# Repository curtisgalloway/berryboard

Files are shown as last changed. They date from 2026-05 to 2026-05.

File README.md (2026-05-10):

# Berryboard

A Raspberry Pi HAT+ for ROV (remotely operated vehicle) control, with an RP2350B co-processor for hard real-time servo and sensor management.

## Overview

Berryboard sits on top of a Raspberry Pi 4 or 5 and handles the latency-sensitive workload that the Linux kernel can't guarantee: PWM servo output, sensor polling, and leak detection. The RPi handles high-level control logic over UART; the RP2350B handles everything that needs deterministic timing.

```
┌─────────────────────────────────────────────┐
│                  Raspberry Pi               │
│                  (host computer)            │
└──────────────┬──────────────────────────────┘
               │ 40-pin HAT header
┌──────────────▼──────────────────────────────┐
│                  Berryboard                  │
│                                             │
│  RP2350B ────── 8× servo outputs (PWM)      │
│           ────── IMU (ICM-42688-P, SPI)     │
│           ────── Magnetometer (MMC5983MA)   │
│           ────── 2× leak sensors (ADC)      │
│           ────── Servo power monitor (ADC)  │
│                                             │
│  TPS2121 power mux                          │
│    IN1: XT30 external servo power           │
│    IN2: RPi 5V from header                  │
│    OUT: 5V system rail                      │
│                                             │
│  6× QWIIC connectors                        │
│    3× on RPi I2C1 (GPIO2/3 on header)       │
│    3× on RP2350B I2C                        │
└─────────────────────────────────────────────┘
```

## Hardware Features

| Feature | Detail |
|---|---|
| Form factor | 65 × 56 mm RPi HAT+ |
| Co-processor | RP2350B (dual Arm Cortex-M33 / RISC-V, 520 KB SRAM) |
| Flash | W25Q16JVSS 2 MB QSPI (RP2350B) |
| EEPROM | 24LC32 (HAT ID, I2C0) |
| Servo outputs | 8 channels — 3× 1×8 Dupont block (signal / power / GND) |
| Servo power | XT30 connector, monitored via ADC |
| IMU | ICM-42688-P 6-axis (accel + gyro), SPI to RPi |
| Magnetometer | MMC5983MA 3-axis, I2C to RPi |
| QWIIC | 6× JST-SH 1 mm (3 RPi + 3 MCU) |
| Leak detection | 2× probes → RP2350B ADC |
| Status LED | WS2812B RGB (RP2350B GPIO12) |
| USB-C | USB 2.0 to RP2350B (programming / debug edge connector) |
| SWD | 4-pin header (J21) |
| Host link | UART (GPIO14/15 on 40-pin header); optional USB-C |
| Power | 5V from XT30 or RPi header, muxed by TPS2121 |
| 3.3V | AP2112K LDO from 5V system rail |

## Servo Connector

The 8 servo channels use three color-coded 1×8 Dupont headers placed side-by-side:

```
Pin:     1    2    3    4    5    6    7    8
         ┌────┬────┬────┬────┬────┬────┬────┐
Yellow   │ S0 │ S1 │ S2 │ S3 │ S4 │ S5 │ S6 │ S7 │  Signal
         ├────┼────┼────┼────┼────┼────┼────┤────┤
Red      │+V  │+V  │+V  │+V  │+V  │+V  │+V  │+V  │  SERVO_PWR
         ├────┼────┼────┼────┼────┼────┼────┤────┤
Black    │GND │GND │GND │GND │GND │GND │GND │GND │  GND
         └────┴────┴────┴────┴────┴────┴────┘────┘
```

Pin 1 = servo channel 1 (SERVO_0 net). Plug a standard 3-pin servo Dupont connector into any column.

## Repository Contents

| File | Description |
|---|---|
| `berryboard.kicad_sch` | Schematic |
| `berryboard.kicad_pcb` | PCB layout |
| `berryboard-custom.kicad_sym` | Custom KiCad symbols (TPS2121, ICM-42688-P, MMC5983MA) |
| `sym-lib-table` | KiCad symbol library table |

## Status

- [x] Schematic complete (0 ERC errors)
- [x] Footprints assigned
- [ ] PCB layout and routing
- [ ] Design rule check
- [ ] BOM verification (JLCPCB availability)
- [ ] Bring-up and testing

## Tools

Designed with [KiCad](https://www.kicad.org/) 9.x.

## License

Hardware design files are released under [CERN Open Hardware Licence Version 2 – Permissive (CERN-OHL-P)](https://ohwr.org/cern_ohl_p_v2.txt).

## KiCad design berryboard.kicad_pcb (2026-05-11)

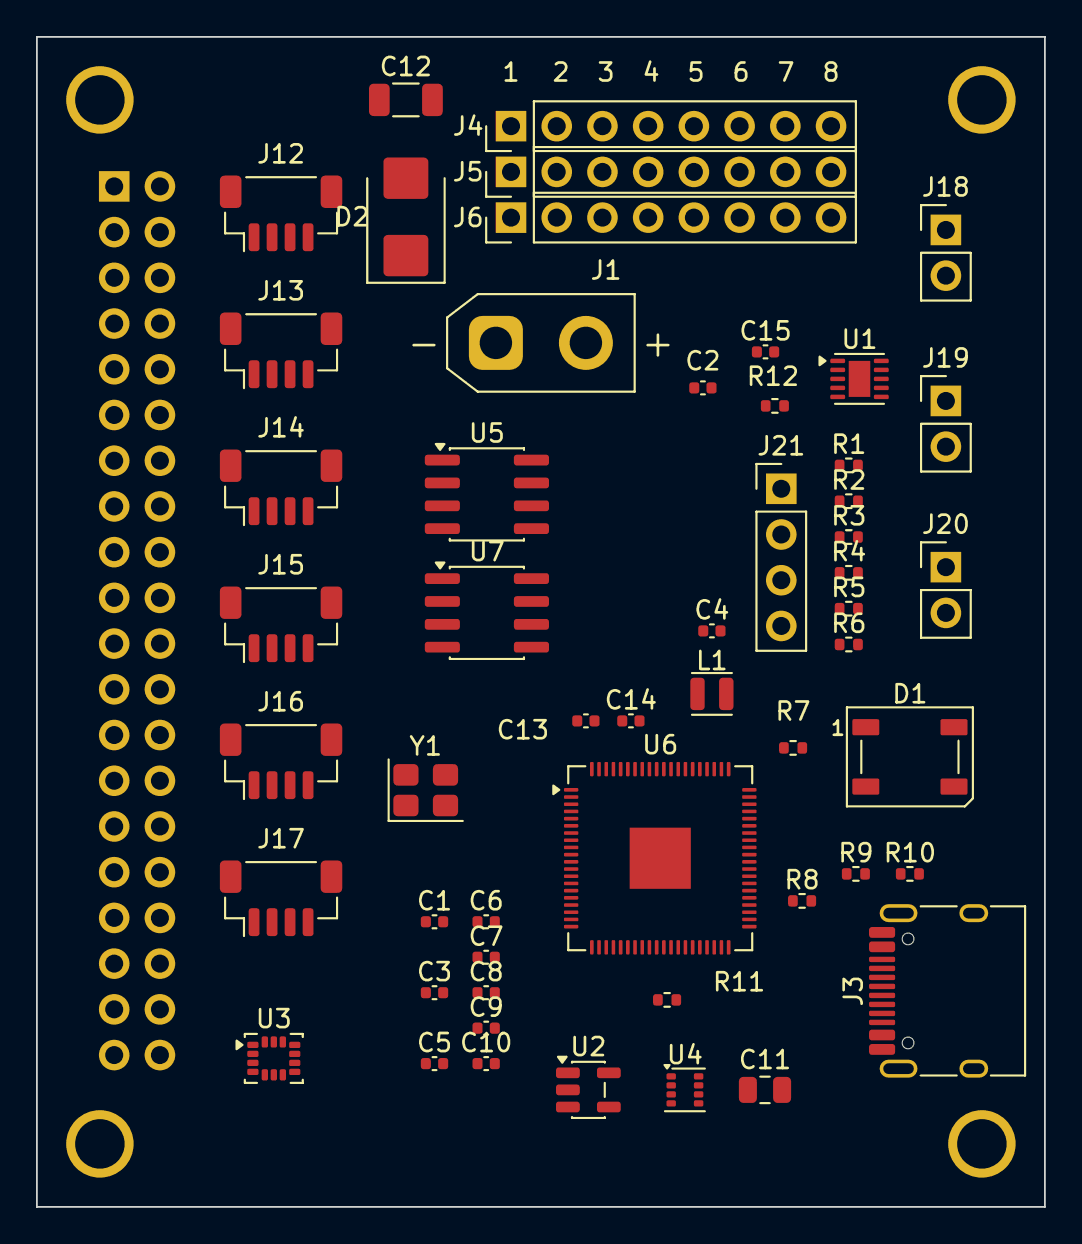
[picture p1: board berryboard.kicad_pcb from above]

Board: 2 copper layers, 56.0 x 65.0 mm, 58 parts (1 on the bottom side), 53 nets, no tracks yet.

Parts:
C1, C5, C6, C7, C8, C9: 100nF; C_0402_1005Metric
C2, C4, C15: 4.7uF; C_0402_1005Metric
C3, C10: 10uF; C_0402_1005Metric
C11: 47uF; C_0805_2012Metric
C12: 100uF; C_1206_3216Metric
C13, C14: 15pF; C_0402_1005Metric
D1: WS2812B; LED_WS2812B_PLCC4_5.0x5.0mm_P3.2mm
D2: SMBJ7.5A; D_SMB
J1: XT30_SERVO_PWR; AMASS_XT30UPB-F_1x02_P5.0mm_Vertical
J2: RPi_GPIO_40P; PinSocket_2x20_P2.54mm_Vertical
J3: USB_C_RP2350; USB_C_Receptacle_HRO_TYPE-C-31-M-12
J4: SERVO_SIG; PinHeader_1x08_P2.54mm_Vertical
J5: SERVO_PWR; PinHeader_1x08_P2.54mm_Vertical
J6: SERVO_GND; PinHeader_1x08_P2.54mm_Vertical
J12: QWIIC_RPI_1; JST_SH_BM04B-SRSS-TB_1x04-1MP_P1.00mm_Vertical
J13: QWIIC_RPI_2; JST_SH_BM04B-SRSS-TB_1x04-1MP_P1.00mm_Vertical
J14: QWIIC_RPI_3; JST_SH_BM04B-SRSS-TB_1x04-1MP_P1.00mm_Vertical
J15: QWIIC_MCU_1; JST_SH_BM04B-SRSS-TB_1x04-1MP_P1.00mm_Vertical
J16: QWIIC_MCU_2; JST_SH_BM04B-SRSS-TB_1x04-1MP_P1.00mm_Vertical
J17: QWIIC_MCU_3; JST_SH_BM04B-SRSS-TB_1x04-1MP_P1.00mm_Vertical
J18: LEAK_1; PinHeader_1x02_P2.54mm_Vertical
J19: LEAK_2; PinHeader_1x02_P2.54mm_Vertical
J20: HAT_5V_IN; PinHeader_1x02_P2.54mm_Vertical
J21: SWD; PinHeader_1x04_P2.54mm_Vertical
L1: AOTA-B201610S3R3-101-T; L_Wuerth_PMCI-201610
MH1, MH2, MH3, MH4: MountingHole_2.75mm
R1, R2: 5.1k; R_0402_1005Metric
R3, R4, R5, R6: 4.7k; R_0402_1005Metric
R7: 220k; R_0402_1005Metric
R8: 100k; R_0402_1005Metric
R9, R10: 27; R_0402_1005Metric
R11: 1k; R_0402_1005Metric
R12: 33; R_0402_1005Metric
U1: TPS2121; WSON-10-1EP_2.5x2.5mm_P0.5mm_EP1.2x2mm
U2: AP2112K-3.3; SOT-23-5
U3: ICM-42688-P; LGA-14_3x2.5mm_P0.5mm_LayoutBorder3x4y
U4: MMC5983MA; Broadcom_LGA-8_2x2mm_P0.5mm
U5: 24LC32; SOIC-8_3.9x4.9mm_P1.27mm
U6: RP2350B; QFN-80-1EP_10x10mm_P0.4mm_EP3.4x3.4mm
U7: W25Q16JVSS; SOIC-8_3.9x4.9mm_P1.27mm
Y1: ABM8-272-T3; Crystal_SMD_3225-4Pin_3.2x2.5mm

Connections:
/+3.3V_RPI: J2.1, J2.17
/+3V3: C2.1, C3.1, C5.1, C6.1, C7.1, C8.1, J12.2, J13.2, J14.2, J15.2, J16.2, J17.2, J21.1, R3.1, R4.1, R5.1, R6.1, R12.1, U2.5, U3.5, U3.6, U4.4, U5.8, U6.5, U6.15, U6.24, U6.29, U6.35, U6.41, U6.50, U6.59, U6.60, U6.64, U6.68, U6.69, U6.76, U7.8
/+5V: C9.1, C10.1, D1.1, J3.A4, J3.A9, J3.B4, J3.B9, U1.6, U2.1, U2.3
/+5V_EXT: J20.1, U1.2, U1.3
/+5V_RPI: J2.2, J2.4, U1.1, U1.4
/FLASH_CLK: U6.71, U7.6
/FLASH_CS: U6.75, U7.1
/FLASH_IO0: U6.72, U7.5
/FLASH_IO1: U6.74, U7.2
/FLASH_IO2: U6.73, U7.3
/FLASH_IO3: U6.70, U7.7
/I2C0_SCL: J2.28, U5.6
/I2C0_SDA: J2.27, U5.5
/I2C1_SCL: J2.5, J12.4, J13.4, J14.4, R6.2, U4.5
/I2C1_SDA: J2.3, J12.3, J13.3, J14.3, R5.2, U4.6
/IMU_INT1: J2.36, U3.3
/LEAK_ADC0: J18.1, U6.52
/LEAK_ADC1: J19.1, U6.53
/MCU_AVDD: C15.1, R12.2, U6.61
/MCU_DVDD: C1.1, C4.1, L1.2, U6.10, U6.32, U6.51, U6.65
/MCU_LX: L1.1, U6.63
/MCU_SCL: J15.4, J16.4, J17.4, R4.2, U6.9
/MCU_SDA: J15.3, J16.3, J17.3, R3.2, U6.8
/MMC_C1: C11.1, U4.8
/MMC_C2: C11.2, U4.3
/NEOPIXEL: D1.4, U6.11
/SERVO_0: J4.7, U6.77
/SERVO_1: J4.6, U6.78
/SERVO_2: J4.5, U6.79
/SERVO_3: J4.4, U6.80
/SERVO_4: J4.3, U6.1
/SERVO_5: J4.2, U6.2
/SERVO_6: J4.1, U6.3
/SERVO_MON: R7.2, R8.1, U6.54
/SERVO_PWR: C12.1, D2.2, J1.1, J5.1, J5.2, J5.3, J5.4, J5.5, J5.6, J5.7, R7.1
/SPI0_CE0: J2.24, U3.12
/SPI0_MISO: J2.21, U3.9
/SPI0_MOSI: J2.19, U3.10
/SPI0_SCLK: J2.23, U3.11
/SWCLK: J21.4, U6.33
/SWDIO: J21.2, U6.34
/UART_RX: J2.10, U6.6
/UART_TX: J2.8, U6.7
/USB_CC1: J3.A5, R1.1
/USB_CC2: J3.B5, R2.1
/USB_DM: J3.A7, J3.B7, R10.1
/USB_DM_MCU: R10.2, U6.66
/USB_DP: J3.A6, J3.B6, R9.1
/USB_DP_MCU: R9.2, U6.67
/XIN: C13.1, U6.30, Y1.1
/XOUT: C14.1, R11.1, Y1.2
/XOUT_MCU: R11.2, U6.31
GND: C1.2, C2.2, C3.2, C4.2, C5.2, C6.2, C7.2, C8.2, C9.2, C10.2, C12.2, C13.2, C14.2, C15.2, D1.3, D2.1, J1.2, J2.6, J2.9, J2.14, J2.20, J2.25, J2.30, J2.34, J2.39, J3.A1, J3.A8, J3.A12, J3.B1, J3.B8, J3.B12, J3.SH, J6.1, J6.2, J6.3, J6.4, J6.5, J6.6, J6.7, J12.1, J13.1, J14.1, J15.1, J16.1, J17.1, J18.2, J19.2, J20.2, J21.3, R1.2, R2.2, R8.2, U1.5, U1.7, U1.9, U2.2, U3.4, U3.7, U3.8, U3.13, U4.1, U4.2, U5.1, U5.2, U5.3, U5.4, U5.7, U6.62, U6.81, U7.4

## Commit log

2026-05-09 Add complete berryboard schematic — custom ROV control HAT for RPi 4/5
    Initial schematic for a custom ROV flight-controller HAT compatible with
    Raspberry Pi 4 and 5 (65×56mm HAT form factor, 40-pin GPIO header).
    Components placed and connected:
    - RPi 40-pin GPIO header (J2) with all power, SPI, I2C, and UART nets labeled
    - RP2350B MCU (U6): GPIO0-7 → 8 servo channels, GPIO8/9 UART, GPIO10/11 I2C,
    GPIO12 WS2812B, GPIO40-43 ADC (leak sensors, servo power monitor)
    - ICM-42688-P IMU (U3) on SPI0 with INT1 to RPi GPIO35
    - MMC5983MA magnetometer (U4) on RPi I2C1
    - 24LC32 HAT ID EEPROM (U5) on RPi I2C0
    - W25Q16JVSS 2MB SPI flash (U7) on RP2350B QSPI
    - TPS2121 dual-input 5V power mux (U1): I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
    [berryboard.kicad_pcb, berryboard.kicad_sch]
2026-05-09 Assign footprints to all schematic components
    Assigns KiCad footprints to every real component in the schematic,
    completing the schematic phase before PCB layout:
    ICs:
    - U1 TPS2121: Texas_Instruments:Texas_Instruments_WSON-10_2.5x3mm_P0.5mm
    - U2 AP2112K-3.3: Package_TO_SOT_SMD:SOT-23-5
    - U3 ICM-42688-P: Package_LGA:LGA-14_3x3mm_P0.5mm (custom)
    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
    [berryboard.kicad_sch]
2026-05-09 Fix footprint assignments — correct names for KiCad standard library
    Five footprints were assigned names that don't exist in the installed
    KiCad library. Corrected to actual library footprint names:
    - U1 TPS2121: WSON-10-1EP_3x3mm (wrong) → WSON-10-1EP_2.5x2.5mm_P0.5mm_EP1.2x2mm
    (TPS2121 is 2.5×2.5mm, not 3×3mm)
    - U3 ICM-42688-P: LGA-14_2.5x3.0mm_P0.5mm_LayoutBorder3x5y (non-existent) →
    LGA-14_3x2.5mm_P0.5mm_LayoutBorder3x4y (closest standard match)
    - U4 MMC5983MA: LGA-8_2.0x2.0mm_P0.5mm_LayoutBorder2x4y (non-existent) →
    OptoDevice:Broadcom_LGA-8_2x2mm_P0.5mm (closest 2×2mm 0.5mm-pitch LGA-8;
    pad layout should be verified against MMC5983MA datasheet)
    - U5 24LC32: SOT-23-5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
    [berryboard.kicad_sch]
2026-05-09 Initialize PCB layout — board outline, mounting holes, all footprints placed
    - Added 65×56mm Edge.Cuts board outline (RPi HAT spec)
    - Added 4× M2.5 NPTH mounting holes at (3.5,3.5), (3.5,52.5),
    (61.5,3.5), (61.5,52.5) — matches RPi HAT mechanical spec
    - Synced schematic netlist to board: all 47 real components placed
    (3 PWR_FLAG symbols correctly excluded from board)
    - 12 warnings for JST SH footprint mounting pads (MP) with no net
    assignment — expected/harmless for mechanical pads
    Components are currently in a pile at the board origin; placement and
    routing are the next steps.
    [berryboard.kicad_pcb]
2026-05-09 Center board outline on A4 page
    Move Edge.Cuts rectangle and mounting holes from (0,0) origin to
    (116,77)-(181,133), centering the 65×56mm HAT on the 297×210mm A4 page.
    [berryboard.kicad_pcb]
2026-05-09 Rotate board 90° — 56mm wide × 65mm tall, recentered on A4 page
    The GPIO header (J2) runs along the long (65mm) axis, so the board
    must be portrait orientation (56×65) not landscape (65×56).
    Board outline: (120.5, 72.5) – (176.5, 137.5) on A4 page
    Mounting holes: (124,76), (173,76), (124,134), (173,134)
    — still 3.5mm from each corner per RPi HAT+ spec
    [berryboard.kicad_pcb]
2026-05-10 Fix J1 footprint to AMASS XT30UPB-F; drop unused 3x8 custom footprint
    J1 (servo power connector) was incorrectly assigned a generic 2-pin
    pin header. Updated to Connector_AMASS:AMASS_XT30UPB-F_1x02_P5.0mm_Vertical,
    which matches the XT30 connector specified in the design.
    Dropped the berryboard-custom.pretty/PinHeader_3x08_P2.54mm_Vertical footprint
    — design changed to three separate 1x8 color-coded Dupont headers (signal,
    power, ground) instead of a single 3x8 header, so the custom footprint is no
    longer needed.
    Also includes KiCad-populated ERC rule settings and layer visibility prefs
    from berryboard.kicad_pro and berryboard.kicad_prl.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
    [berryboard.kicad_sch]
2026-05-10 Replace 8 individual servo headers with 3×1x8 color-coded headers
    Removed J4–J11 (eight Conn_01x03 3-pin servo headers, one per channel)
    and replaced them with three Conn_01x08 1×8 headers:
    J4 SERVO_SIG — signal pins for servo channels 0–7 (yellow header)
    J5 SERVO_PWR — SERVO_PWR net × 8 (red header)
    J6 SERVO_GND — GND net × 8 (black header)
    Footprint: Connector_PinHeader_2.54mm:PinHeader_1x08_P2.54mm_Vertical
    on all three. On the PCB the three headers will be placed adjacently to
    form a physical 3×8 block accepting standard colored Dupont housings.
    Silkscreen will label positions 1–8 as servo channels.
    Net assignments: J4 pin 1 = SERVO_0 (ch 1) through pin 8 = S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
    [berryboard.kicad_sch]
2026-05-10 Update PCB: remove old servo connectors, add 3x 1x8 headers
    Synced PCB from schematic after servo header redesign:
    - Deleted J4–J11 footprints (eight 1x3 servo headers) from board
    - Added J4 (SERVO_SIG), J5 (SERVO_PWR), J6 (SERVO_GND) as
    PinHeader_1x08_P2.54mm_Vertical footprints, ready for placement
    [berryboard.kicad_pcb]
2026-05-10 Add README; fix sym-lib-table to use portable KIPRJMOD path
    README covers: project overview, block diagram, hardware feature table,
    servo connector pinout, repo contents, and build status checklist.
    sym-lib-table had an absolute path (/Users/curtisg/src/berryboard/...)
    for the custom symbol library. Replaced with ${KIPRJMOD}/... so the
    library resolves correctly for anyone who clones the repo.
    License: CERN-OHL-P v2 (standard for open hardware designs).
2026-05-10 Remove 24 orphaned net labels left over from servo header redesign
    When J4-J11 were deleted, their attached net labels (SERVO_0-7,
    SERVO_PWR x8, GND x8) at x=271.78 became floating. Removed all 24.
    Leak sensor labels at the same x (J18/J19, y>140) are preserved.
    [berryboard.kicad_sch]
2026-05-11 PCB: fix servo header spacing and order; schematic: add SERVO_PWR protection and SERVO_MON divider
    PCB changes:
    - Reorder J4/J5/J6 so signal (J4) is at top (y=77.5), power (J5) at y=80.04,
    ground (J6) at y=82.58 — matches yellow/red/black color convention
    - Fix row spacing to exactly 2.54mm so a 3-pin Dupont housing mates all three
    rows simultaneously
    - Align all three X coordinates to 143.22
    - Add F.SilkS channel labels "1"–"8" above the servo header block
    Schematic changes:
    - Add D2 (SMBJ7.5A TVS diode) from SERVO_PWR to GND for transient protection
    - Add C12 (100µF bulk capacitor) on SERVO_PWR for servo current decoupling
    - Add R7/R8 (220k/100k) voltage divider: SERVO_PWR → SE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
    [berryboard.kicad_pcb, berryboard.kicad_sch]
2026-05-11 Fix PCB silkscreen text syntax — remove invalid (justify center)
    KiCad PCB format does not accept "center" as a justify value; center
    alignment is the default and the justify line should be omitted entirely.
    [berryboard.kicad_pcb]
2026-05-11 Add project-level Claude Code hook: validate KiCad files before git commit
    Before any git commit, the hook runs kicad-cli to export staged .kicad_pcb
    and .kicad_sch files. If any file fails to parse, the commit is blocked with
    a clear error message. This catches syntax errors (like the invalid
    "justify center" issue) before they reach the repo.
    Hook lives in .claude/hooks/validate-kicad.sh; project settings in
    .claude/settings.json wire it as a PreToolUse hook on Bash commands.
2026-05-11 Connector footprint updates: female GPIO socket, vertical QWIIC
    J2 (RPi 40-pin GPIO header):
    - Footprint: PinHeader_2x20_P2.54mm_Vertical → PinSocket_2x20_P2.54mm_Vertical
    - PCB layer: F.Cu → B.Cu (female socket on bottom of board to mate with RPi)
    - All F.SilkS/F.Fab/F.CrtYd references flipped to B.* within the footprint block
    J12–J17 (six QWIIC/JST-SH connectors):
    - Footprint: JST_SH_SM04B-SRSS-TB_1x04-1MP_P1.00mm_Horizontal →
    JST_SH_BM04B-SRSS-TB_1x04-1MP_P1.00mm_Vertical
    - Changed in both schematic and PCB
    [berryboard.kicad_pcb, berryboard.kicad_sch]
2026-05-11 RP2350B design rules compliance: SMPS, USB termination, crystal circuit
    Changes to bring schematic into full compliance with Raspberry Pi Foundation
    "Hardware design with RP2350" guide (build 2024-10-15):
    SMPS (Chapter 2):
    - L1: change inductor from generic 10uH/0603 to mandated Abracon
    AOTA-B201610S3R3-101-T 3.3uH in 0806 (2016 metric) package.
    This specific polarized part is required; any substitution risks
    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
    [berryboard.kicad_sch]
2026-05-11 Place all design-guide-critical components near U6
    Per the RP2350 Hardware Design Guide:
    USB resistors (27Ω series on USB_DP/DM):
    - R9 → (153.5, 94.0) — 2.8mm from USB_DP pin 67
    - R10 → (156.5, 94.0) — 2.8mm from USB_DM pin 66
    SMPS switching regulator components:
    - L1 (3.3µH Abracon inductor) → (156.24, 91.5) — between VREG_VIN/LX pads
    - C2 (4.7µF VREG cap) → (154.5, 90.0) — near L1/VREG pins
    - C4 (4.7µF VREG cap) → (158.0, 90.0) — near L1/VREG pins
    - R12 (33Ω VREG_AVDD filter) → (159.5, 93.5) — close to VREG_AVDD pin 61
    - C15 (4.7µF VREG_AVDD cap) → (159.5, 91.5) — after R12 on filtered rail
    Crystal oscillator components:
    - C13 (15pF XIN load cap) → (1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
    [berryboard.kicad_pcb, berryboard.kicad_sch]
2026-05-11 Complete schematic wiring — connect all U6 power pins and peripheral nets
    - Added net labels to all RP2350B (U6) power/SMPS pins:
    MCU_DVDD → DVDD (pins 10/32/51 stacked) and VREG_FB (pin 65)
    MCU_LX → VREG_LX (pin 63)
    MCU_AVDD → VREG_AVDD (pin 61)
    +3V3 → VREG_VIN (pin 64)
    GND → VREG_PGND (pin 62)
    - All labels placed at exact pin endpoints via componentRef+pinNumber snapping
    to guarantee electrical connectivity
    - Wired all QSPI/Flash signals (FLASH_CS, FLASH_CLK, FLASH_IO0-3),
    crystal (XIN/XOUT), USB differential pairs (USB_DP_MCU/USB_DM_MCU),
    SWD debug (SWCLK/SWDIO), servo GPIO signals, I2C/SPI/UART buses,
    and ADC/GPIO nets to U6 pins
    - Added servo protection (D2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
    [berryboard.kicad_sch]
2026-05-11 Wire PWR_GOOD, MAG_DRDY, and SPARE_ADC0 to MCU and connector
    - PWR_GOOD (AP2112K-3.3 power-good output) → U6 GPIO9 (pin 12)
    - MAG_DRDY (MMC5983MA magnetometer DRDY interrupt) → U6 GPIO10 (pin 13)
    - SPARE_ADC0 → new J22 1×2 header (same style as J18/J19 leak connectors)
    placed adjacent to the existing ADC connector bank at (276.86, 130.51)
    All three "Label connected to only one pin" ERC warnings are now resolved.
    ERC: 96 violations total — 6 errors are known J4/J5/J6 pin-8 false positives,
    remainder are off-grid label placement warnings and library version mismatches.
    [berryboard.kicad_sch]
2026-05-11 Manual PCB layout adjustments
    Component placement refined by hand in KiCad after initial automated
    placement — adjusted positions for better routing, clearance, and
    alignment with RP2350 design guide recommendations.
    [berryboard.kicad_pcb]
2026-05-11 Fix real ERC errors: J4/J5/J6 pin 8 unconnected on all servo connectors
    SERVO_7, SERVO_PWR, and GND labels were each placed 2.54mm (one pin
    pitch) above pin 1 of their respective connectors instead of at pin 8.
    This left pin 8 of J4 (SERVO_SIG), J5 (SERVO_PWR), and J6 (SERVO_GND)
    genuinely unconnected — one servo channel missing from each rail.
    Moved each misplaced label to the exact pin 8 endpoint using
    componentRef+pinNumber snapping. ERC now shows zero errors (90 warnings
    only: off-grid placements and library version mismatches).
    [berryboard.kicad_sch]
